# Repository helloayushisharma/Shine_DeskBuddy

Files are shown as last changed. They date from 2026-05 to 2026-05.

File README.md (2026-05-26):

<p align="center">
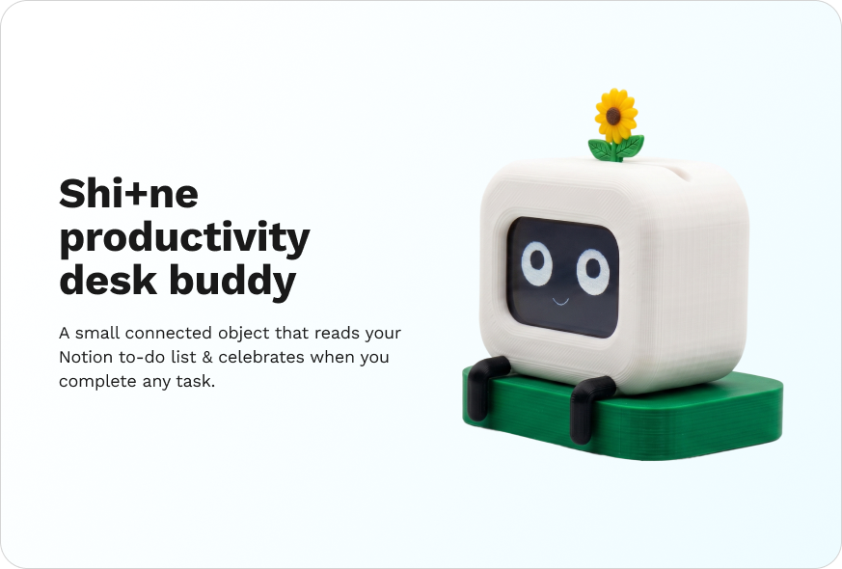
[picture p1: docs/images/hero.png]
Shi+ne, a small white robot with a sunflower on its head, sitting on a desk
  
</p>

<h1 align="center">
  Shi+ne
</h1>

<p align="center">
  A productivity desk companion that watches your Notion to-do list
  and raises a flower when you finish a task.
</p>

<p align="center">
  <a href="docs/BUILD_GUIDE.md">Build guide</a> ·
  <a href="docs/WIRING.md">Wiring reference</a>
</p>

---

## What it is

Shi+ne sits on the corner of your desk and watches your Notion to-do list. When you mark a task complete, it lifts a sunflower from its head on a servo arm, animates a celebration on its LCD face, and returns to a soft idle state. Tap it once and it acknowledges the touch. Tap it five times and it gets visibly annoyed.

Part status display, part desk pet, part accountability companion. Built on an Adafruit ESP32 V2 Feather, a 3.5" SPI touch LCD, a micro servo, and the Notion API.

## Hardware

| Component | Notes |
|---|---|
| Adafruit ESP32 V2 Feather | Built-in WiFi, 2MB PSRAM (needed for off-screen sprite rendering) |
| 3.5" ILI9486 SPI touch LCD | 480×320, resistive touch |
| Smraza SG90 micro servo | Or any equivalent 5V hobby servo |
| USB-C cable and 5V wall adapter | Powers the whole device |
| PLA filament | White for body, dark green for base, yellow for flower |
| Perfboard, 14× silicone-jacketed wires, M2 fasteners | For the final assembly |

## Quick start

If you just want to flash and go:

1. Clone the repo
2. Open `firmware/shine/shine.ino` in Arduino IDE
3. Install the four required libraries: TFT_eSPI, ESP32Servo, ArduinoJson, HTTPClient
4. Configure TFT_eSPI's `User_Setup.h` for the ILI9486 board (see the build guide)
5. Fill in your WiFi credentials and Notion API details at the top of the file
6. Flash to an ESP32 V2 Feather wired according to [docs/WIRING.md](docs/WIRING.md)

For the full process including 3D printing the body and final assembly, see [docs/BUILD_GUIDE.md](docs/BUILD_GUIDE.md).

## Wiring

The display ships with documentation written for Raspberry Pi. Translating to the ESP32 V2 took most of a week the first time around. The full table is in [docs/WIRING.md](docs/WIRING.md). Two non-obvious things to know up front:

- The backlight runs on 5V, not 3.3V. Route it to USB VBUS or the screen stays dark.
- LCD_CS and TP_CS are different chip selects on the same SPI bus. Confusing them gives you a working display with no touch, or working touch with no display.

## Architecture

Shi+ne runs three concurrent loops on the ESP32, coordinated by a state machine:

- **Display loop** renders expression sprites into a PSRAM-backed off-screen buffer, then flips to the LCD via SPI. Off-screen rendering removes the visible flash between frames.
- **Polling loop** runs on core 0 as a FreeRTOS task. It hits the Notion API every three seconds, parses the JSON response with streaming, and writes the count under a mutex. The main loop never blocks on HTTP.
- **Interaction loop** reads the touch controller, debounces, and classifies single taps from rapid multi-taps.

Shi+ne also includes a multi-app mode system: the main Shi+ne face, a Flappy Bird game, and a Windows 10-style tile launcher accessed by holding the screen for five seconds.

## Repository structure

```
firmware/   Arduino sketches and TFT_eSPI configuration notes
cad/        Print-ready STL files
docs/       Build guide, wiring reference, images, GIFs
```

## Forking and modifying

Shi+ne is dual-licensed so the source code and the hardware/design work can each use the license that suits them best:

- **Firmware source code** (everything under `firmware/`) — **MIT License**. Reuse it in any project, open or closed, as long as you keep the copyright notice.
- **Hardware designs, CAD files, build guide, wiring reference, README, and images** — **Creative Commons Attribution-ShareAlike 4.0 International (CC BY-SA 4.0)**. Remix the body, fork the docs, build variants — and share your derivative work back under the same license.

Both halves require attribution: credit the original project (Shi+ne), name the original authors (Ayushi Sharma and Neha Sadaye), and link back to this repository.

If you build a variant, open an issue on this repo and link to it. We would love to see what you make.

## License

Dual-licensed: **MIT** for the firmware source code, **CC BY-SA 4.0** for the hardware designs, documentation, and other assets. See [LICENSE](LICENSE) for the overview and [LICENSES/](LICENSES/) for the full legal text of each.

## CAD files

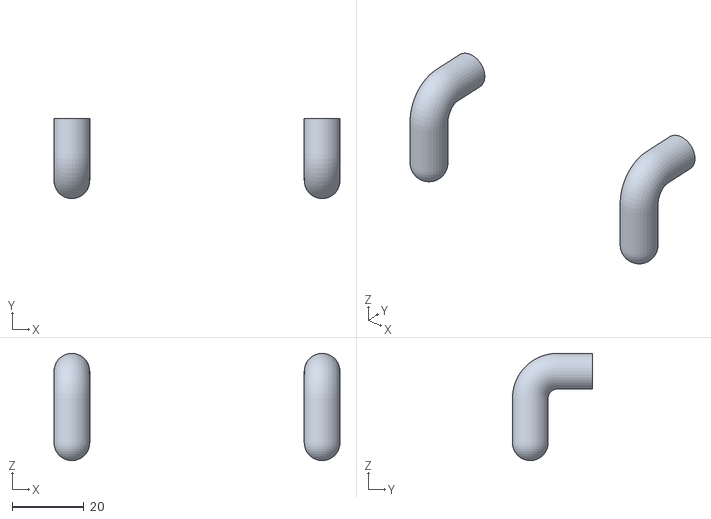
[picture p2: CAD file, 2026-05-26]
cad/legs.stl
80.0 x 22.4 x 30.0

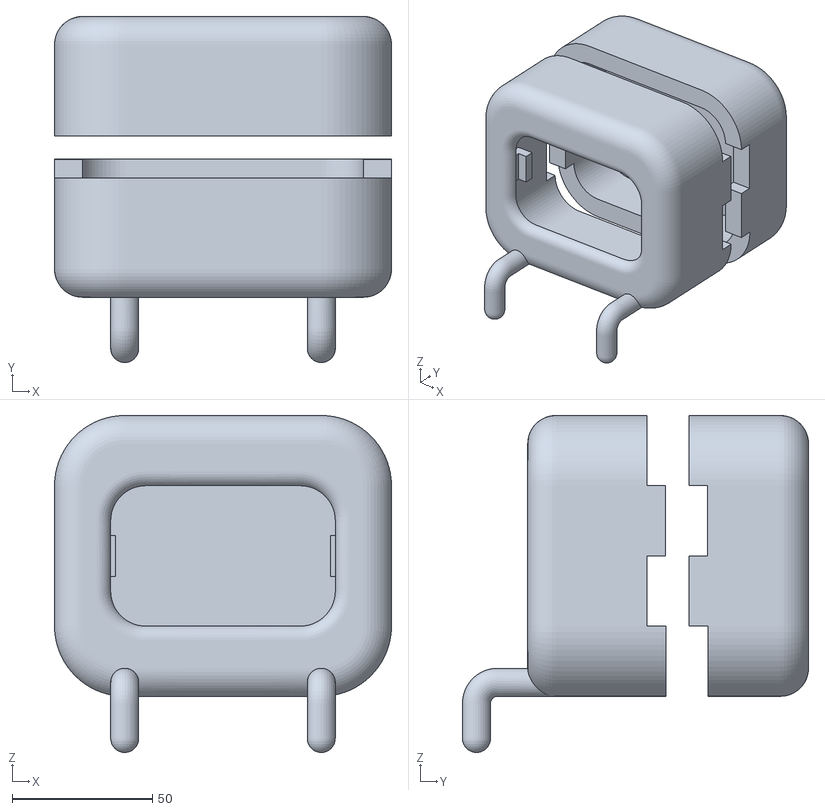
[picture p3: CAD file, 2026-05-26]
cad/shine_body.stl
120.0 x 123.2 x 120.0

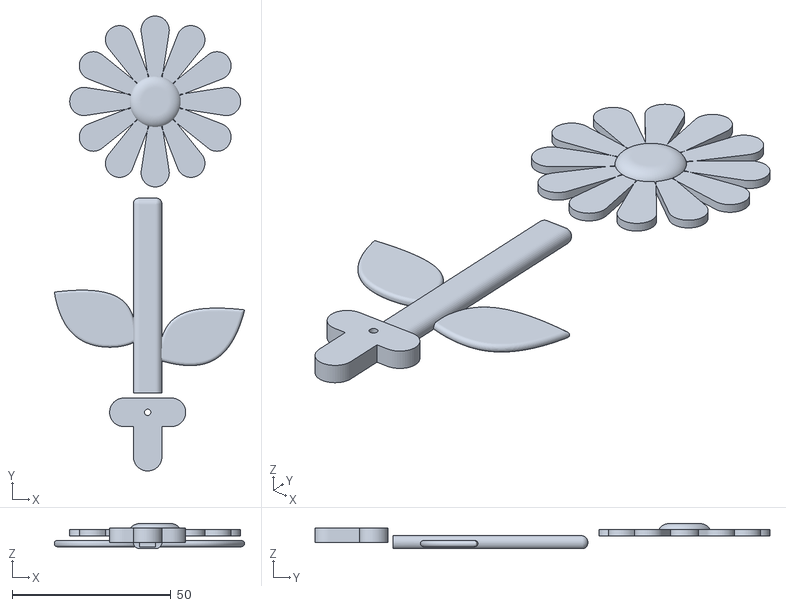
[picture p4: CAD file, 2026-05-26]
cad/servo_topper.stl
60.0 x 143.4 x 8.00

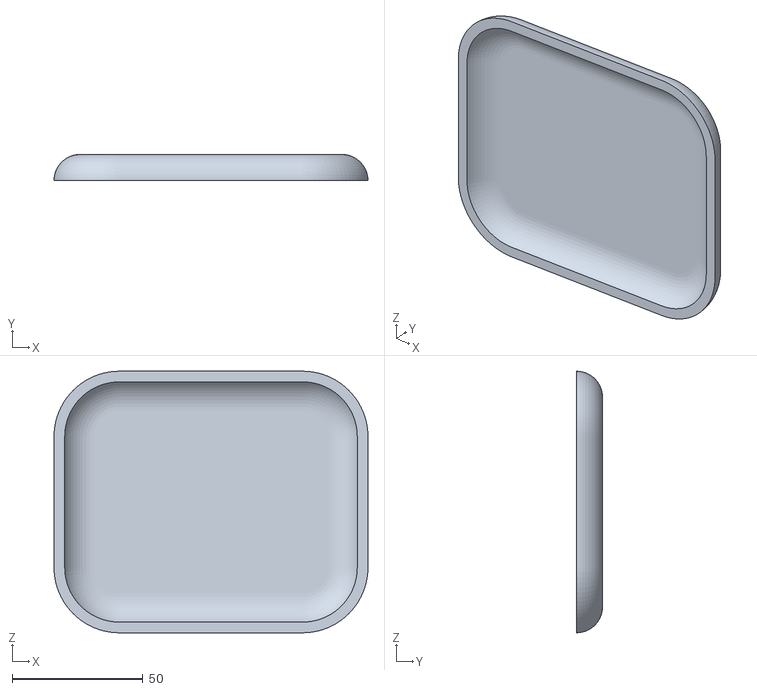
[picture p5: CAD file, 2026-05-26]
cad/back_curve.stl
120.0 x 10.0 x 100.0

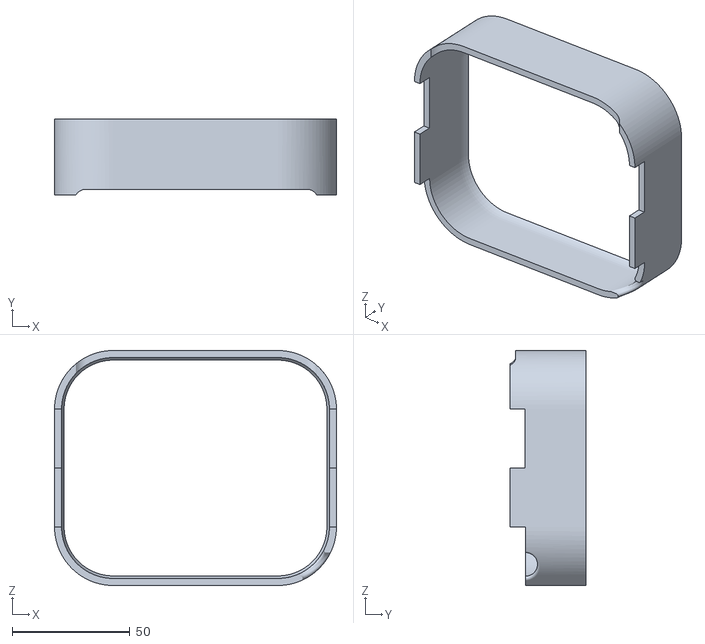
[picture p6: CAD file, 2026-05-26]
cad/back_1.stl
120.0 x 32.5 x 100.0

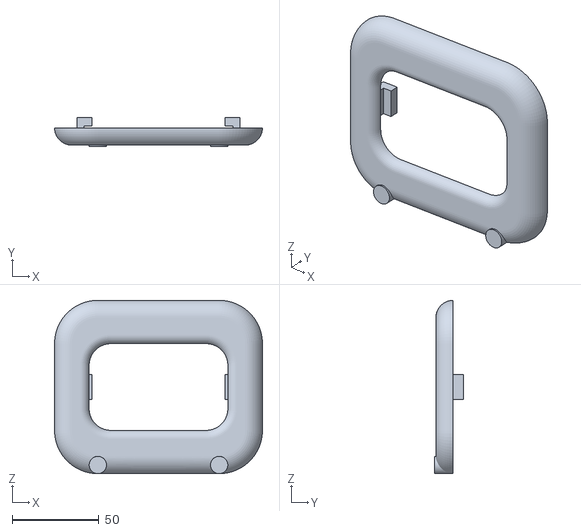
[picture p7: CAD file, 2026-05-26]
cad/front_curve.stl
120.0 x 16.8 x 100.0

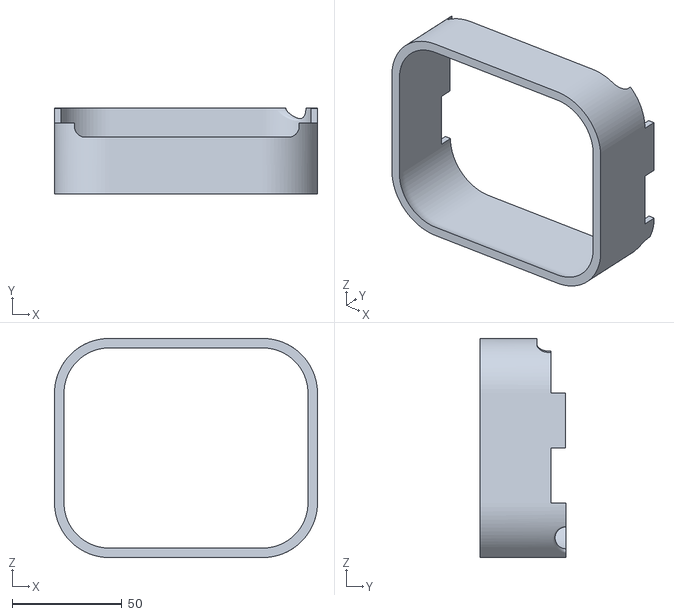
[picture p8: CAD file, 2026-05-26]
cad/front_1.stl
120.0 x 39.3 x 100.0

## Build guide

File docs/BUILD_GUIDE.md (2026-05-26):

# Building Shi+ne

Three flows: getting the electronics to work, printing the body, and bringing the two together. Allow a few hours for the first, several hours of print time for the second, and roughly an evening for the third.

## What is Shi+ne?

Shi+ne is a small connected object that lives on your desk and reads your Notion to-do list. When you complete a task, it lifts a sunflower from its head, animates a celebration on its LCD face, and returns to a soft idle state. Tap it once and it acknowledges the touch with a tickled expression. Tap it five times and it gets visibly annoyed.

There are other features. You can play Flappy Bird on it. You can watch it react to tasks being added or unchecked in Notion.

---

## Part 1 · Technical flow

The goal of this part is a fully working Shi+ne on a breadboard, connected to your Notion to-do list, before you commit to any soldering or 3D printing.

### Step 1 · Gather the parts

```
1× Adafruit ESP32 V2 Feather
1× 3.5" ILI9486 SPI touch LCD (480×320, resistive touch)
1× Smraza SG90 (or equivalent) micro servo
1× USB-C cable and 5V wall adapter
1× breadboard, jumper wires, multimeter
1× soldering iron, solder, perfboard (for the final assembly)
1× M2 fastener set
3D printing services or equivalent
PLA filament (white and dark green recommended)
```

### Step 2 · Set up the development environment

Install the Arduino IDE.

Add the ESP32 board package via Boards Manager. Install these libraries through the Library Manager:

```
TFT_eSPI      — display driver
ESP32Servo    — non-blocking servo control
ArduinoJson   — Notion API response parsing
HTTPClient    — comes with the ESP32 package
```

Open `TFT_eSPI/User_Setup.h` in your Arduino libraries folder and configure it for the ILI9486 board. The key defines are:

```cpp
#define ILI9486_DRIVER
#define TFT_MISO  MISO
#define TFT_MOSI  MOSI
#define TFT_SCLK  SCK
#define TFT_CS    15
#define TFT_DC    27
#define TFT_RST   33
#define TOUCH_CS  14

#define SPI_FREQUENCY        27000000
#define SPI_READ_FREQUENCY   10000000
#define SPI_TOUCH_FREQUENCY  2500000
```

Keep `RPI_DISPLAY_TYPE` enabled for this panel. Do not define `TFT_WR` (the standard fast `pushBlock` path is what Shi+ne is tuned for).

### Step 3 · Wire the display on a breadboard

The display ships with documentation written for Raspberry Pi. Translating to the ESP32 V2 took most of a week the first time around. Use this table.

| LCD Pin | LCD Function | ESP32 V2 Pin |
|---|---|---|
| 19 | MOSI | MO |
| 21 | MISO | MI |
| 23 | SCK | SCK |
| 24 | LCD_CS | 15 |
| 18 | DC | 27 |
| 22 | RST | 33 |
| 26 | TP_CS | 14 |
| 1, 17 | Logic power | 3V |
| 6 | Ground | GND |
| Backlight | LED+ | USB / VBUS |

Two things you absolutely have to know up front. **The LCD has two independent power systems.** Logic and touch run on 3.3V, the backlight runs on 5V. Route the backlight to USB VBUS, not the 3V pin, or your screen will be alive and invisible. Second, **LCD_CS and TP_CS are separate chip-select lines on the same SPI bus.** Confusing them will give you a display that draws but ignores touch, or vice versa.

### Step 4 · First display test

Flash a simple color-fill sketch from the `TFT_eSPI` examples folder. If the screen is bright and showing colors, the wiring is correct. If the screen is dark, check the backlight wire is on VBUS. If the screen is bright white or random pixels, check the chip-select wires.

### Step 5 · Touch test

Run the `Touch_calibrate` example from the `TFT_eSPI` library. Touch the four corners as prompted. Note the five calibration values it prints to the Serial Monitor. You will paste them into the main firmware in Step 8. The values Shi+ne ships with are `{300, 3600, 300, 3600, 1}`, but every panel is slightly different.

### Step 6 · Wire the servo

```
Servo signal → GPIO 32
Servo power  → USB / VBUS (5V)
Servo ground → GND
```

Flash a simple servo sweep sketch to confirm motion. If the servo jitters or fails to hold position, your 3V regulator is probably trying to power it. Move the power wire to VBUS.

### Step 7 · Set up Notion

This step has more onboarding friction than the soldering. Three substeps.

**Create an integration.** Go to `notion.so/my-integrations`, click New Integration, name it Shi+ne, set it to Internal. Copy the integration token that appears. It starts with `secret_`.

**Create the to-do database.** In Notion, create a new database with two properties: a Title property called `Name`, and a Checkbox property called `Done`. Add a few test tasks.

**Share the database with the integration.** Open the database, click the three dots in the top right, choose Connections, and add the Shi+ne integration you just made. Without this step the API will return an empty result and you will lose an evening debugging the wrong thing.

**Find your database ID.** Open the database in a browser. The URL looks like `notion.so/yourname/336ea5e0a8d04...?v=...`. The 32-character string between the last slash and the question mark is your database ID.

### Step 8 · Configure the firmware

Open `firmware/shine/shine.ino`. Fill in the four constants at the top:

```cpp
const char* WIFI_SSID     = "your network name";
const char* WIFI_PASSWORD = "your network password";
const char* NOTION_TOKEN  = "secret_...";
const char* DATABASE_ID   = "336ea5e0...";
```

Paste your touch calibration values into the `setup()` function:

```cpp
uint16_t calData[5] = {300, 3600, 300, 3600, 1};  // your values from Step 5
```

_Do not commit these credentials to GitHub._ The repo's `.gitignore` already excludes the common local-config patterns, but if you change the structure, double-check before pushing.

### Step 9 · Flash and verify end to end

Connect the ESP32 over USB-C, select the board and port, and click Upload. Watch the Serial Monitor at 115200 baud during boot. You should see, in order:

1. The display boot animation (eyes opening, looking around, settling)
2. WiFi connection within ten seconds
3. A Notion poll log line showing the count of tasks fetched
4. The idle face with the task counter at the bottom

Mark a task complete in Notion. Within three seconds Shi+ne should run the celebration sequence and raise the flower. Tap the screen once for the tickled face, five times rapidly for the agitated face.

If any of this fails, the Serial Monitor will tell you which step broke. WiFi errors, Notion 404s, and JSON parse failures are all logged clearly.

### Step 10 · Solder to perfboard

Once everything works on the breadboard, transfer the wiring to perfboard with permanent soldered joints. Fourteen connections in total. Check each one with a multimeter on continuity and voltage modes. Two of the joints on our first build were cold solder joints and only revealed themselves when the display froze ninety seconds into a session, so do this carefully.

---

## Part 2 · Form flow

The goal of this part is a clean printed body, ready to receive the electronics.

### Step 1 · The CAD files

The `cad/` directory of the repo contains print-ready STL files:

```
cad/shine_body.stl       Main body shell
cad/front_1.stl          Front face panel
cad/front_curve.stl      Front curve detail
cad/back_1.stl           Back panel
cad/back_curve.stl       Back curve detail
cad/legs.stl             Base legs
cad/servo_topper.stl     Servo mount and flower-stem holder
```

If you want to modify dimensions, the STLs can be imported into Fusion 360, Blender, or any mesh editor. The Fusion 360 source files are not included in this release.

### Step 2 · Understand the four-part structure

The body is split into multiple printable parts that bolt together:

```
1. Main body         holds the LCD and the internal electronics
2. Front / back panels   close the cavity around the screen
3. Legs              the base with the feet
4. Servo topper      the arm that rises through the slot for the flower
```

The split exists because earlier single-piece prints failed at an internal corner where the LCD bezel met the body. PLA does not cooperate with sharp internal edges in long unsupported spans. Splitting the body into parts let each surface print in its preferred orientation. Do not try to print this as one piece. The split is the design.

### Step 3 · Slicer settings

These are the settings the final prints used. Adjust for your printer.

```
Material        PLA (white for body, dark green for base)
Layer height    0.16 mm
Infill          20%
Wall thickness  3 perimeters (1.2 mm)
Print speed     50 mm/s
Top/bottom      6 layers
Supports        Tree, only where the slicer flags overhangs over 50°
Bed adhesion    Brim, 5 mm
```

Print the body parts in white. Print the legs in dark green. Print the servo topper in white.

### Step 4 · Print order and orientation

Print in this order so you can dry-fit as you go:

1. **Legs first.** Simplest geometry. If they print clean, your slicer settings are dialed in.
2. **Back and front panels next.** Lets you check fit between panels before printing the more time-consuming parts.
3. **Main body third.** This is the longest print. Orient with the LCD bezel facing up.
4. **Servo topper last.** Short print. Print two in case the first servo attachment fails.

### Step 5 · Post-process

Remove supports gently. The LCD bezel area is the most fragile, work slowly there. Sand any visible seams with 400-grit paper. Dry-fit the LCD into the body bezel before assembly. The fit should be snug. If it is loose, add a small strip of double-sided foam tape to the inside lip. If it is tight, sand the inside of the bezel by a few tenths of a millimeter.

### Step 6 · The flower

The sunflower itself is a separate print, or store-bought, your call. If you don't have yellow filament, print in white and paint with yellow. Glue the petals and center together with super glue. Glue the assembled flower to the top of the servo topper.

### Step 7 · Test the LCD bezel fit before going further

Before any electronics go in, slot the unwired LCD into the body bezel. It should sit flush, with the screen facing forward. If anything is off, fix the print or the model before continuing. Once the wiring is in, going back is painful.

---

## Part 3 · Final assembly flow

The goal of this part is a working Shi+ne on your desk.

### Step 1 · Mount the LCD

Slot the LCD into the body bezel from inside. Secure with the small clip features the model includes, or with two dabs of hot glue if the friction fit needs help. The screen face should sit flush with the outer surface of the bezel.

### Step 2 · Route the wiring

The 14-wire ribbon between the LCD and the ESP32 should pass through the channel on the inside of the body, down into the lower cavity. Leave roughly 3 cm of slack so you can lift the upper body without disconnecting anything.

### Step 3 · Mount the ESP32

The ESP32 sits inside the body cavity on the small mounting posts. Secure with M2 screws. The USB-C port should align with the cutout on the back of the body so you can plug in power without disassembling anything.

### Step 4 · Mount the servo and attach the flower stem

The servo sits in the dedicated bay inside the body, with its output shaft pointing up through the flower-stem slot. Secure with two M2 screws. Slide the servo topper onto the servo's output shaft. The topper includes a friction-fit socket sized for the SG90 spline.

### Step 5 · Servo calibration

Power on the device. The flower should sit at the down position (flush with or just below the top surface of the body). If it sits too high or too low, adjust the `FLAG_DOWN` constant in the firmware. If the flower at full rise extends too far above the body, lower `FLAG_UP`. Defaults are 0 and 90 degrees respectively.

The first build broke a flower stem at this step because the servo slammed against the mechanical stop at full speed. The firmware now uses a critically-damped spring simulation on the descent, but it is still worth dry-running the full motion with the flower detached the first time, then attaching once you confirm the angles are right.

### Step 6 · Assemble the panels

Bolt the front and back panels to the main body. Slot the assembled body into the legs base. The base holds the body by friction, no fasteners needed.

### Step 7 · Final boot test on the desk

Plug Shi+ne in. Watch the boot animation. Confirm:

1. Eyes open, look around, settle
2. WiFi connects within ten seconds
3. The task counter shows your current Notion state
4. Idle blink fires every four to seven seconds
5. A single tap on the screen produces the tickled face
6. Marking a task complete in Notion raises the flower within three seconds
7. The flower descends smoothly without slamming

### Step 8 · Hold the screen for five seconds

Five seconds of held touch on the Shi+ne face opens the Win10-style tile launcher. From there, switch into Flappy Bird. Hold for five seconds in either mode to return.

### Step 9 · Put it on your desk

If you got this far, your Shi+ne is real. Place it somewhere you will see it during work. Mark a task complete. Watch the flower rise. The first time it works on your actual desk, in front of your actual to-do list, is the moment the project becomes the thing you designed.

---

## What you have at the end

A working desk companion that watches your Notion database, raises a flower when you finish something, and pretends to be ticklish if you tap its screen. The full source, STL files, and this guide are open. Fork it, modify it, change the personality, swap the flower for something else, port the integration to a different service.

If you build one, open an issue on this repo with a photo. We would love to see it on your desk.

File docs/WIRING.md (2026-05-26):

# Wiring reference

The display ships with documentation written for Raspberry Pi. This table translates the pin mapping to the ESP32 V2 Feather's named breakout labels.

## Pin map: ILI9486 LCD on ESP32 V2 Feather

| LCD Pin | LCD Function | ESP32 V2 Pin |
|---|---|---|
| 19 | MOSI (SPI data out) | MO |
| 21 | MISO (SPI data in) | MI |
| 23 | SCK (SPI clock) | SCK |
| 24 | LCD_CS (display chip select) | 15 |
| 18 | DC (data / command select) | 27 |
| 22 | RST (display reset) | 33 |
| 26 | TP_CS (touch chip select) | 14 |
| 1, 17 | Logic power | 3V |
| 6 | Ground | GND |
| Backlight | LED+ (5V rail) | USB / VBUS |

## Servo

| Servo wire | ESP32 V2 Pin |
|---|---|
| Signal (orange/yellow) | GPIO 32 |
| Power (red) | USB / VBUS (5V) |
| Ground (brown/black) | GND |

## Two non-obvious things to know

**The backlight runs on 5V.** Logic and touch run on 3.3V. The backlight LED runs on 5V and pulls more current than the 3.3V regulator on the ESP32 can supply. Route the backlight to USB VBUS, not the 3V pin, or the screen will stay dark while everything else works.

**LCD_CS and TP_CS are different chip selects.** The display and the touch controller share MOSI, MISO, and SCK, but listen on different chip-select lines. Mixing them up gives you a working display with no touch input, or working touch with a blank display.

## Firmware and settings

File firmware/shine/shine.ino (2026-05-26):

// SPDX-License-Identifier: MIT
// Copyright (c) 2026 Ayushi Sharma and Neha Sadaye
//
// ============================================================
// Shi+ne - by Ayushi and Neha
// ============================================================
// Multi-app mode system with Win10 Mobile tile launcher:
//   - Shi+ne mode (Notion desk companion)
//   - Flappy Bird game
//   - Win10 Mobile tile home screen (hold 5s to access)
//   - Turnstile transition animations between modes
//   - Sprite memory freed/reallocated on mode switch
// ============================================================


#include <TFT_eSPI.h>
#include <SPI.h>
#include <ESP32Servo.h>
#include <WiFi.h>
#include <WiFiClientSecure.h>
#include <HTTPClient.h>
#include <ArduinoJson.h>


// ============================================================
// FILL THESE IN
// ============================================================
const char* WIFI_SSID     = "Your WiFi name";
const char* WIFI_PASSWORD = "Your WiFi password";
const char* NOTION_TOKEN  = "Notion Token";
const char* DATABASE_ID   = "Database ID";


const char* CHECKBOX_PROPERTY = "Done";
const char* TITLE_PROPERTY    = "Name";


// ============================================================
// SERVO TUNABLES
// ============================================================
// SERVO_RISE_MODE: 1 = single-write (smoothest), 0 = chunked
#define SERVO_RISE_MODE 0


const int           SERVO_RISE_STEP_DEG   = 15;
const unsigned long SERVO_RISE_STEP_MS    = 40;
const unsigned long SERVO_HOLD_MS         = 10000;


// SERVO_RETURN_MODE: 0 = waypoints, 1 = physics spring
#define SERVO_RETURN_MODE 1


const int           SERVO_RETURN_WAYPOINTS[]   = {40, 15, 5, 0};
const int           SERVO_RETURN_WAYPOINT_COUNT = 4;
const unsigned long SERVO_RETURN_DWELL_MS      = 300;


const float         PHYSICS_SPRING_K  = 7.11f;
const float         PHYSICS_SPRING_D  = 5.33f;
const unsigned long PHYSICS_TICK_MS   = 20;
const float         PHYSICS_DONE_POS  = 0.5f;
const float         PHYSICS_DONE_VEL  = 1.0f;


const unsigned long WIFI_CHECK_MS         = 2000;
const unsigned long WIFI_BACKOFF_START_MS = 5000;
const unsigned long WIFI_BACKOFF_MAX_MS   = 60000;


const int           PUPIL_STEP_PX = 5;
const unsigned long PUPIL_STEP_MS = 25;


// COUNTER_ANIM_MODE: 0 = slot machine, 1 = bounce
#define COUNTER_ANIM_MODE 0


#if COUNTER_ANIM_MODE == 0
 const int           COUNTER_ANIM_FRAMES = 10;
 const unsigned long COUNTER_ANIM_MS     = 35;
#else
 const int           COUNTER_ANIM_FRAMES = 5;
 const unsigned long COUNTER_ANIM_MS     = 50;
#endif


const int           COUNTER_ROLL_FRAMES = COUNTER_ANIM_FRAMES;
const unsigned long COUNTER_ROLL_MS     = COUNTER_ANIM_MS;


const unsigned long TASK_ADDED_SURPRISED_MS = 600;


// ============================================================
// HARDWARE
// ============================================================
TFT_eSPI tft = TFT_eSPI();
Servo flagServo;


#define SERVO_PIN   32
#define FLAG_DOWN   0
#define FLAG_UP     90


// ============================================================
// SCREEN
// ============================================================
const int SW = 480;
const int SH = 320;


const int L_EX = 165;
const int R_EX = 315;
const int EY   = 110;


const int EYE_R   = 56;
const int PUPIL_R = 25;


const int MOUTH_Y = 185;
#define TEXT_ZONE_TOP 220


#define CONF_L_X   5
#define CONF_L_W   55
#define CONF_R_X   420
#define CONF_R_W   55


#define COL_BG    TFT_BLACK
#define COL_WHITE TFT_WHITE
#define COL_PUPIL TFT_BLACK
#define COL_LID   TFT_BLACK
#define COL_DIM   0x6B4D


uint16_t confColors[] = {0xFFE0, 0x07FF, 0x07E0, 0xFBE0, 0xFFFF};
#define NUM_CONF_COLORS 5


// ============================================================
// SPRITES (shi+ne mode — allocated/freed on mode switch)
// ============================================================
TFT_eSprite eyeSpr = TFT_eSprite(&tft);
TFT_eSprite mouthSpr = TFT_eSprite(&tft);
TFT_eSprite confLSpr = TFT_eSprite(&tft);
TFT_eSprite confRSpr = TFT_eSprite(&tft);
TFT_eSprite counterSpr = TFT_eSprite(&tft);


#define EYE_SPR_W (EYE_R * 2 + 6)
#define EYE_SPR_H (EYE_R * 2 + 6)
#define MOUTH_SPR_W 100
#define MOUTH_SPR_H 35
#define COUNTER_SPR_W 320
#define COUNTER_SPR_H 36


// ============================================================
// APP MODE SYSTEM
// ============================================================
enum AppMode { APP_SHINE, APP_FLAPPY, APP_TILES };
AppMode currentApp = APP_SHINE;
bool transitionActive = false;
bool flappyPlaying = false;  // set by flappy.ino when game is active


// Async Notion polling (FreeRTOS task on core 0)
SemaphoreHandle_t notionMutex = NULL;
TaskHandle_t notionTaskHandle = NULL;
volatile bool notionPollBusy     = false;
volatile bool notionResultReady  = false;
int  notionResultDone  = 0;
int  notionResultTotal = 0;
char notionResultTask[64] = "";


// Hold-to-switch detection
bool          holdActive          = false;
unsigned long holdStartTime       = 0;
bool          holdProgressVisible = false;
const unsigned long HOLD_THRESHOLD_MS = 5000;
const uint16_t COL_ACCENT = 0x0479;   // Win10 accent blue (#0078D7)


// Hold circle indicator sprite
const int HOLD_CIRCLE_R    = 22;  // outer radius
const int HOLD_CIRCLE_THICK = 3;  // ring thickness
const int HOLD_SPR_SIZE    = (HOLD_CIRCLE_R + 2) * 2;  // sprite dimensions
TFT_eSprite holdSpr = TFT_eSprite(&tft);
bool holdSprAllocated = false;
int holdSprX = 0, holdSprY = 0;  // screen position of sprite top-left


// ============================================================
// EYE STATE
// ============================================================
int curPupilX = 0, curPupilY = 0;
bool eyesDrawn = false;


// ============================================================
// STATE (shi+ne mode)
// ============================================================
enum BuddyMood {
 MOOD_IDLE, MOOD_HAPPY, MOOD_TASK_ADDED, MOOD_AGITATED,
 MOOD_TICKLE, MOOD_CONNECTING, MOOD_ERROR
};


BuddyMood currentMood = MOOD_CONNECTING;
int completedCount = 0, totalCount = 0;
int previousCount = -1, previousTotal = -1;
String lastTaskName = "";


unsigned long lastPollTime = 0;
unsigned long moodStartTime = 0;
unsigned long lastAnimFrame = 0;
const unsigned long POLL_INTERVAL     = 3000;
const unsigned long HAPPY_DURATION    = 7000;
const unsigned long ADDED_DURATION    = 4000;
const unsigned long AGITATED_DURATION = 3000;
const unsigned long TICKLE_DURATION   = 1200;


// Servo state machine
enum ServoState { SERVO_S_IDLE, SERVO_S_RISING, SERVO_S_HOLDING, SERVO_S_RETURNING };
ServoState    servoState        = SERVO_S_IDLE;
int           servoCurrentAngle = 0;
unsigned long lastServoStep     = 0;
unsigned long servoHoldStart    = 0;
int           returnWaypointIndex = 0;


// Physics return state
float         physicsP        = 0;
float         physicsV        = 0;
unsigned long lastPhysicsTick = 0;


// Task-added sub-phase
enum TaskAddedPhase { TA_SURPRISED, TA_NORMAL };
TaskAddedPhase taskAddedPhase      = TA_NORMAL;
unsigned long  taskAddedPhaseStart = 0;


// WiFi watchdog state
bool          wifiOffline            = false;
bool          wifiIndicatorOnScreen  = false;
unsigned long lastWifiCheck          = 0;
unsigned long lastReconnectAttempt   = 0;
unsigned long currentBackoffMs       = WIFI_BACKOFF_START_MS;


// Pupil saccade tween
int           targetPupilX  = 0, targetPupilY = 0;
bool          pupilMoving   = false;
unsigned long lastPupilStep = 0;


// Counter slot-machine roll
int  displayedDone = -1, displayedTotal = -1;
bool counterRolling = false;
int  counterRollFrame = 0;
unsigned long lastCounterRollFrame = 0;
int  counterRollFromDone, counterRollFromTotal;
int  counterRollToDone,   counterRollToTotal;


int idleStep = 0;
unsigned long lastIdleStep = 0;
const unsigned long IDLE_STEP_TIME = 1200;


bool isBlinking = false;
int blinkFrame = 0;
unsigned long lastBlinkFrame = 0;


int happyPhase = 0;
unsigned long lastHappySwap = 0;
bool happyFaceIsCresc = false;
int happyTaskCount = 1;


// Touch
int tapCount = 0;
unsigned long lastTapTime = 0;
bool touchWasDown = false;


#define NUM_CONFETTI 9
struct Confetti {
 float x, y, speed;
 int size;
 uint16_t color;
 bool leftSide;
};
Confetti conf[NUM_CONFETTI];
bool confettiActive = false;


// Bee state (drawn by shine_mode.ino, freed by freeShineSprites)
TFT_eSprite beeSpr = TFT_eSprite(&tft);
bool beeSprAllocated = false;
bool beeActive = false;
float beeT = 0;
int beePrevX = -50, beePrevY = -50;
unsigned long lastBeeFrame = 0;
unsigned long beeStartTime = 0;
unsigned long nextBeeTime = 0;
int beeWingFrame = 0;


// ============================================================
// SPRITE ALLOCATION / DEALLOCATION
// ============================================================
void allocateShineSprites() {
 eyeSpr.setColorDepth(16);
 eyeSpr.createSprite(EYE_SPR_W, EYE_SPR_H);


 mouthSpr.setColorDepth(16);
 mouthSpr.createSprite(MOUTH_SPR_W, MOUTH_SPR_H);


 confLSpr.setColorDepth(16);
 confLSpr.createSprite(CONF_L_W, SH);


 confRSpr.setColorDepth(16);
 confRSpr.createSprite(CONF_R_W, SH);


 counterSpr.setColorDepth(16);
 counterSpr.createSprite(COUNTER_SPR_W, COUNTER_SPR_H);


 Serial.printf("shi+ne sprites allocated. Free PSRAM: %d\n", ESP.getFreePsram());
}


void freeShineSprites() {
 eyeSpr.deleteSprite();
 mouthSpr.deleteSprite();
 confLSpr.deleteSprite();
 confRSpr.deleteSprite();
 counterSpr.deleteSprite();
 freeBeeSprite();
 beeActive = false;


 Serial.printf("shi+ne sprites freed. Free PSRAM: %d\n", ESP.getFreePsram());
}


// ============================================================
// ASYNC NOTION POLL (runs on core 0 — WiFi core)
// ============================================================
void notionPollTaskFn(void* param) {
 for (;;) {
   ulTaskNotifyTake(pdTRUE, portMAX_DELAY);  // sleep until signaled


   if (WiFi.status() != WL_CONNECTED) {
     notionPollBusy = false;
     continue;
   }


   WiFiClientSecure client;
   client.setInsecure();
   HTTPClient http;


   char url[128];
   snprintf(url, sizeof(url), "https://api.notion.com/v1/databases/%s/query", DATABASE_ID);


   http.useHTTP10(true);  // disable chunked encoding so stream is raw JSON
   http.begin(client, url);


   char authHeader[128];
   snprintf(authHeader, sizeof(authHeader), "Bearer %s", NOTION_TOKEN);
   http.addHeader("Authorization", authHeader);
   http.addHeader("Notion-Version", "2022-06-28");
   http.addHeader("Content-Type", "application/json");


   int httpCode = http.POST("{\"sorts\":[{\"timestamp\":\"last_edited_time\",\"direction\":\"descending\"}]}");;
   Serial.printf("Notion async: %d\n", httpCode);


   if (httpCode == 200) {
     // Stream parsing — no 30KB String allocation
     WiFiClient* stream = http.getStreamPtr();
     DynamicJsonDocument doc(24576);
     DeserializationError err = deserializeJson(doc, *stream);


     if (!err) {
       JsonArray results = doc["results"];
       int localTotal = results.size();
       int localDone = 0;
       char localTask[64] = "";


       for (int i = 0; i < localTotal; i++) {
         JsonObject page = results[i];
         bool isDone = page["properties"][CHECKBOX_PROPERTY]["checkbox"] | false;
         if (isDone) {
           localDone++;
           // Capture FIRST completed task name (Notion returns newest first)
           if (localTask[0] == '\0') {
             const char* name = page["properties"][TITLE_PROPERTY]["title"][0]["plain_text"];
             if (name) snprintf(localTask, sizeof(localTask), "%s", name);
           }
         }
       }


       // Copy results under mutex
       if (xSemaphoreTake(notionMutex, pdMS_TO_TICKS(100))) {
         notionResultDone = localDone;
         notionResultTotal = localTotal;
         strncpy(notionResultTask, localTask, sizeof(notionResultTask));
         notionResultReady = true;
         xSemaphoreGive(notionMutex);
       }
     } else {
       Serial.printf("JSON parse error: %s\n", err.c_str());
     }
   } else {
     Serial.printf("Notion API error: %d\n", httpCode);
   }
   http.end();
   notionPollBusy = false;
 }
}


// ============================================================
// BOOT ANIMATION STATE
// ============================================================
int  bootPhase = 0;
unsigned long bootPhaseStart = 0;
unsigned long bootStart = 0;
bool bootComplete = false;
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
void loop() {
 unsigned long now = millis();


 // Boot animation runs until complete
 if (!bootComplete) {
   runBootAnimation(now);
   return;
 }


 // WiFi watchdog runs in ALL modes
 checkWifi(now);


 // Servo state machine runs in ALL modes (flower may be mid-return)
 updateServo(now);


 // Transition animation takes over the entire loop
 if (transitionActive) {
   runTransitionFrame(now);
   return;
 }


 // Cheap touch check: getTouchRawZ (~0.1ms) instead of getTouch (~1.5-20ms)
 // Only do full coordinate read when tiles mode needs X/Y for hit testing
 uint16_t touchX = 0, touchY = 0;
 bool isTouching = (tft.getTouchRawZ() > 500);
 if (isTouching && currentApp == APP_TILES) {
   // Need actual coordinates for tile hit testing
   isTouching = tft.getTouch(&touchX, &touchY);
 }


 // Hold-to-switch runs in shi+ne and flappy (not tiles)
 if (currentApp != APP_TILES) {
   updateHoldDetection(now, isTouching);
 }


 // Mode dispatch
 switch (currentApp) {
   case APP_SHINE:
     loopShine(now, isTouching);
     delay(2);  // yield to WiFi stack
     break;
   case APP_FLAPPY:
     loopFlappy(now, isTouching);
     break;
   case APP_TILES:
     loopTiles(now, isTouching, touchX, touchY);
     delay(10);
     break;
 }
}


// ============================================================
// HOLD DETECTION — 5s hold triggers tile launcher
// Uses a circular arc indicator at screen center
// ============================================================
void updateHoldDetection(unsigned long now, bool touching) {
 if (touching) {
   if (!holdActive) {
     holdActive = true;
     holdStartTime = now;


     // Allocate hold circle sprite (small — ~2KB)
     if (!holdSprAllocated) {
       holdSpr.setColorDepth(16);
       void* hp = holdSpr.createSprite(HOLD_SPR_SIZE, HOLD_SPR_SIZE);
       if (hp) holdSprAllocated = true;
     }
     // Position: screen center
     holdSprX = SW / 2 - HOLD_SPR_SIZE / 2;
     holdSprY = SH / 2 - HOLD_SPR_SIZE / 2;
   }


   unsigned long elapsed = now - holdStartTime;


   if (elapsed >= HOLD_THRESHOLD_MS) {
     holdActive = false;
     eraseHoldCircle();
     freeHoldSprite();
     Serial.println("Hold detected — transitioning to tiles");
     beginTransition(APP_TILES);
     return;
   }


   // Draw circular arc progress (clockwise from 12 o'clock)
   if (elapsed > 200) {  // small dead zone so quick taps don't flash
     drawHoldCircle((float)elapsed / (float)HOLD_THRESHOLD_MS);
     holdProgressVisible = true;
   }


 } else {
   if (holdActive) {
     holdActive = false;
     if (holdProgressVisible) {
       eraseHoldCircle();
       holdProgressVisible = false;
     }
     freeHoldSprite();
   }
 }
}


// Draw the arc into the sprite and push it
void drawHoldCircle(float progress) {
 if (!holdSprAllocated) return;


 int cx = HOLD_SPR_SIZE / 2;
 int cy = HOLD_SPR_SIZE / 2;


 holdSpr.fillSprite(TFT_MAGENTA);


 // Dark backing ring
 holdSpr.fillCircle(cx, cy, HOLD_CIRCLE_R, 0x2104);
 holdSpr.fillCircle(cx, cy, HOLD_CIRCLE_R - HOLD_CIRCLE_THICK - 2, TFT_MAGENTA);


 // Progress arc using TFT_eSPI's built-in drawArc
 // drawArc angles: 0 = 6 o'clock, clockwise. 12 o'clock = 180.
 uint32_t startDeg = 180;
 uint32_t endDeg = startDeg + (uint32_t)(progress * 360.0f);
 if (endDeg > 540) endDeg = 540;  // clamp at full circle


 holdSpr.drawArc(cx, cy, HOLD_CIRCLE_R, HOLD_CIRCLE_R - HOLD_CIRCLE_THICK,
                 startDeg % 360, endDeg % 360, COL_ACCENT, TFT_MAGENTA, false);


 // Handle wrap-around: if endDeg > 360+180=540, it wraps past 6 o'clock
 if (endDeg > 360) {
   holdSpr.drawArc(cx, cy, HOLD_CIRCLE_R, HOLD_CIRCLE_R - HOLD_CIRCLE_THICK,
                   0, endDeg % 360, COL_ACCENT, TFT_MAGENTA, false);
 }


 holdSpr.pushSprite(holdSprX, holdSprY, TFT_MAGENTA);
}


// Erase the circle area by redrawing what was behind it
void eraseHoldCircle() {
 if (currentApp == APP_SHINE) {
   // Redraw the area — for shi+ne, just fill with black and let the
   // next idle frame redraw the face elements if they overlap
   tft.fillRect(holdSprX, holdSprY, HOLD_SPR_SIZE, HOLD_SPR_SIZE, COL_BG);
   // Force eyes + mouth redraw on next frame
   eyesDrawn = false;
 } else if (currentApp == APP_FLAPPY) {
   // Fill with sky color (the circle is in the sky area)
   tft.fillRect(holdSprX, holdSprY, HOLD_SPR_SIZE, HOLD_SPR_SIZE, 0x6EBE);
 }
}


void freeHoldSprite() {
 if (holdSprAllocated) {
   holdSpr.deleteSprite();
   holdSprAllocated = false;
 }
}


// Switch to tiles with animation
void switchToTiles() {
 beginTransition(APP_TILES);
}


// ============================================================
// CLEAR SCREEN HELPER (preserves offline indicator)
// ============================================================
void clearScreen() {
 tft.fillScreen(COL_BG);
 wifiIndicatorOnScreen = false;
 if (wifiOffline) drawOfflineIndicator();
}


// ============================================================
// SAFE SERVO WRITE
// ============================================================
void safeServoWrite(int angle) {
 flagServo.write(constrain(angle, FLAG_DOWN, FLAG_UP));
}


// Sub-degree write via writeMicroseconds (used by physics return)
void writeServoMicros(float angle) {
 if (angle < (float)FLAG_DOWN) angle = (float)FLAG_DOWN;
 if (angle > (float)FLAG_UP)   angle = (float)FLAG_UP;
 int us = 500 + (int)((angle / 180.0f) * 2000.0f);
 flagServo.writeMicroseconds(us);
}


// ============================================================
// SERVO STATE MACHINE (non-blocking rise -> hold -> return)
// ============================================================
void startServoRise(unsigned long now) {
#if SERVO_RISE_MODE == 1
 safeServoWrite(FLAG_UP);
 servoCurrentAngle = FLAG_UP;
 servoState = SERVO_S_HOLDING;
 servoHoldStart = now;
#else
 servoState = SERVO_S_RISING;
 lastServoStep = now;
#endif
}


void updateServo(unsigned long now) {
 switch (servoState) {
   case SERVO_S_IDLE:
     return;


   case SERVO_S_RISING:
     if (now - lastServoStep < SERVO_RISE_STEP_MS) return;
     lastServoStep = now;
     servoCurrentAngle += SERVO_RISE_STEP_DEG;
     if (servoCurrentAngle >= FLAG_UP) {
       servoCurrentAngle = FLAG_UP;
       servoState = SERVO_S_HOLDING;
       servoHoldStart = now;
     }
     safeServoWrite(servoCurrentAngle);
     break;


   case SERVO_S_HOLDING:
     if (now - servoHoldStart >= SERVO_HOLD_MS) {
#if SERVO_RETURN_MODE == 0
       returnWaypointIndex = 0;
       safeServoWrite(SERVO_RETURN_WAYPOINTS[0]);
       servoCurrentAngle = SERVO_RETURN_WAYPOINTS[0];
       lastServoStep = now;
#else
       physicsP = (float)FLAG_UP;
       physicsV = 0;
       lastPhysicsTick = now;
#endif
       servoState = SERVO_S_RETURNING;
     }
     break;


   case SERVO_S_RETURNING:
#if SERVO_RETURN_MODE == 0
     if (now - lastServoStep < SERVO_RETURN_DWELL_MS) return;
     lastServoStep = now;
     returnWaypointIndex++;
     if (returnWaypointIndex >= SERVO_RETURN_WAYPOINT_COUNT) {
       servoState = SERVO_S_IDLE;
       happyTaskCount = 1;
       return;
     }
     safeServoWrite(SERVO_RETURN_WAYPOINTS[returnWaypointIndex]);
     servoCurrentAngle = SERVO_RETURN_WAYPOINTS[returnWaypointIndex];
#else
     {
       unsigned long elapsed = now - lastPhysicsTick;
       if (elapsed < PHYSICS_TICK_MS) return;
       lastPhysicsTick = now;
       if (elapsed > 50) elapsed = 50;  // stability clamp
       float dt = elapsed / 1000.0f;


       float err = physicsP - (float)FLAG_DOWN;
       float acc = -PHYSICS_SPRING_K * err - PHYSICS_SPRING_D * physicsV;
       physicsV += acc * dt;
       physicsP += physicsV * dt;


       if (fabs(err) < PHYSICS_DONE_POS && fabs(physicsV) < PHYSICS_DONE_VEL) {
         physicsP = (float)FLAG_DOWN;
         writeServoMicros(physicsP);
         servoCurrentAngle = FLAG_DOWN;
         servoState = SERVO_S_IDLE;
         happyTaskCount = 1;
         return;
       }


       writeServoMicros(physicsP);
       servoCurrentAngle = (int)physicsP;
     }
#endif
     break;
 }
}


// ============================================================
// WIFI WATCHDOG (exponential backoff + offline indicator)
// ============================================================
void drawOfflineIndicator() {
 int x = 462, y = 4;
 int w = 14;
 tft.fillTriangle(x + w/2, y, x, y + w, x + w, y + w, TFT_ORANGE);
 tft.drawLine(x + w/2, y + 4, x + w/2, y + w - 4, COL_BG);
 tft.drawLine(x + w/2 - 1, y + 4, x + w/2 - 1, y + w - 4, COL_BG);
 tft.fillCircle(x + w/2, y + w - 2, 1, COL_BG);
 wifiIndicatorOnScreen = true;
}


void clearOfflineIndicator() {
 tft.fillRect(460, 2, 20, 20, COL_BG);
 wifiIndicatorOnScreen = false;
}
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

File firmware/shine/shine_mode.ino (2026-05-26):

// SPDX-License-Identifier: MIT
// Copyright (c) 2026 Ayushi Sharma and Neha Sadaye
//
// ============================================================
// shi+ne MODE — face, moods, touch, confetti, Notion polling,
//               idle animation, blink, saccade, counter roll
// ============================================================
// All globals and #includes live in shine.ino (main file).
// Arduino IDE compiles all .ino files as one translation unit.

// ============================================================
// MAIN SHI+NE LOOP (called from loop() when currentApp == APP_SHINE)
// ============================================================
void loopShine(unsigned long now, bool isTouching) {

  // task-added sub-phase (surprised -> normal text, no delay)
  if (currentMood == MOOD_TASK_ADDED) {
    updateTaskAddedPhase(now);
  }

  if (currentMood == MOOD_HAPPY && (now - moodStartTime > HAPPY_DURATION)) {
    confettiActive = false;
    returnToIdle(now);
  }

  if (currentMood == MOOD_TASK_ADDED && (now - moodStartTime > ADDED_DURATION)) {
    returnToIdle(now);
  }

  if (currentMood == MOOD_AGITATED && (now - moodStartTime > AGITATED_DURATION)) {
    returnToIdle(now);
  }

  if (currentMood == MOOD_TICKLE && (now - moodStartTime > TICKLE_DURATION)) {
    returnToIdle(now);
  }

  // Exclude MOOD_HAPPY from polling. pollNotion() blocks for 1-2s on each
  // HTTPS call, which freezes confetti animation if it happens during HAPPY.
  // --- Async Notion polling: trigger background task, check results ---

  // Trigger a new poll if interval elapsed and no poll in progress
  if (!notionPollBusy && !holdActive &&
      currentMood != MOOD_ERROR && currentMood != MOOD_AGITATED &&
      currentMood != MOOD_TICKLE && currentMood != MOOD_HAPPY &&
      currentMood != MOOD_TASK_ADDED &&
      (now - lastPollTime > POLL_INTERVAL)) {
    lastPollTime = now;
    notionPollBusy = true;
    xTaskNotifyGive(notionTaskHandle);  // wake the background task
  }

  // Check if results are ready (non-blocking)
  if (notionResultReady && xSemaphoreTake(notionMutex, 0)) {
    completedCount = notionResultDone;
    totalCount = notionResultTotal;
    lastTaskName = String(notionResultTask);
    notionResultReady = false;
    xSemaphoreGive(notionMutex);

    // Process results — same trigger logic as before
    if (previousCount >= 0 && completedCount > previousCount) {
      int delta = completedCount - previousCount;

      if (servoState != SERVO_S_IDLE) {
        happyTaskCount += delta;
        if (currentMood != MOOD_HAPPY) {
          currentMood = MOOD_HAPPY;
          moodStartTime = now;
          clearScreen();
          drawHappyCrescents();
          spriteSmile(22, 9);
          happyPhase = 0;
          happyFaceIsCresc = false;
          initConfetti();
        } else {
          moodStartTime = now;
        }
        if (servoState == SERVO_S_RETURNING) {
          startServoRise(now);
        } else if (servoState == SERVO_S_HOLDING) {
          servoHoldStart = now;
        }
        drawCelebrationText(totalCount - completedCount);
      } else {
        happyTaskCount = delta;
        triggerCelebration();
      }
    } else if (previousTotal >= 0 && totalCount > previousTotal && completedCount == previousCount) {
      triggerTaskAdded();
    }
    previousCount = completedCount;
    previousTotal = totalCount;

    if (currentMood == MOOD_IDLE && !counterRolling &&
        (displayedDone != completedCount || displayedTotal != totalCount)) {
      startCounterRoll(displayedDone, displayedTotal, completedCount, totalCount);
    }
  }

  if (currentMood == MOOD_IDLE) {
    // Suppress eye animations during hold (22ms SPI blocks the hold circle)
    if (!holdActive) {
      handleIdleAnimation(now);
      handleSmoothBlink(now);
      handlePupilTween(now);
    }
    handleCounterRoll(now);
  }

  if (currentMood == MOOD_HAPPY) {
    handleHappyAnim(now);
  }

  // touch works during idle AND tickle (so rapid taps still count)
  if (currentMood == MOOD_IDLE || currentMood == MOOD_TICKLE) {
    handleShineTouch(now, isTouching);
  }
}

// Called when entering shi+ne mode from tiles
void enterShineMode() {
  currentMood = MOOD_IDLE;
  tft.fillScreen(COL_BG);
  wifiIndicatorOnScreen = false;

  // Immediate poll to catch up on any changes while away
  pollNotion();
  previousCount = completedCount;
  previousTotal = totalCount;
  displayedDone  = completedCount;
  displayedTotal = totalCount;
  lastPollTime = millis();

  spriteEyes(0, 0);
  spriteSmile(18, 6);
  drawTaskCounter();

  if (wifiOffline) drawOfflineIndicator();

  idleStep = 0;
  lastIdleStep = millis();
  pupilMoving = false;
  eyesDrawn = true;
}

// ============================================================
// RETURN TO IDLE
// ============================================================
void returnToIdle(unsigned long now) {
  currentMood = MOOD_IDLE;
  clearScreen();
  eyesDrawn = false;
  spriteEyes(0, 0);
  spriteSmile(18, 6);

  if (displayedDone >= 0 &&
      (displayedDone != completedCount || displayedTotal != totalCount)) {
    startCounterRoll(displayedDone, displayedTotal, completedCount, totalCount);
  } else {
    drawTaskCounter();
    displayedDone  = completedCount;
    displayedTotal = totalCount;
  }

  idleStep = 0;
  lastIdleStep = now;
  pupilMoving = false;
}

// ============================================================
// TOUCH - tap once = tickle, 5 rapid taps = agitated
// ============================================================
void handleShineTouch(unsigned long now, bool touching) {
  // Suppress taps while user is holding for mode switch
  if (holdActive && (now - holdStartTime > 300)) return;

  if (touching && !touchWasDown) {
    touchWasDown = true;

    if (now - lastTapTime > 4000) {
      tapCount = 0;
    }

    tapCount++;
    lastTapTime = now;
    Serial.printf("Tap %d\n", tapCount);

    if (tapCount >= 5) {
      triggerAgitated();
      tapCount = 0;
      return;
    }

    triggerTickle();
  }

  if (!touching && touchWasDown) {
    touchWasDown = false;
  }
}

// ============================================================
// TICKLE - happy crescents + smile + "it tickles"
// ============================================================
void triggerTickle() {
  currentMood = MOOD_TICKLE;
  moodStartTime = millis();

  clearScreen();
  eyesDrawn = false;

  drawHappyCrescents();
  spriteSmile(22, 9);

  tft.setTextColor(COL_WHITE, COL_BG);
  tft.setTextDatum(TC_DATUM);
  tft.setFreeFont(&FreeSansBold12pt7b);
  tft.drawString("it tickles", SW / 2, TEXT_ZONE_TOP + 20);
}
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
